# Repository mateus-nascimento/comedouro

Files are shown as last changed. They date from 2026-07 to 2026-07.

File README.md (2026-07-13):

# Comedouro — Alimentador de Pets com Porta RFID

Sistema de comedouro automatizado para gatos, com porta controlada por servo e leitora RFID 125 kHz serial. Apenas a tag da **Snow** abre a porta; qualquer outra tag cadastrada ou desconhecida fecha a porta.

---

## Funcionalidades e Comportamento

| Tag detectada | Ação |
|---|---|
| **Snow** (`900200000014659`) | Abre a porta (servo → 90°) |
| **Lilith** (`900200000014611`) | Fecha a porta (servo → 180°) |
| **Sophie** (`900200000014691`) | Fecha a porta (servo → 180°) |
| **Tag desconhecida** | Fecha a porta (servo → 180°) |

### Regras de operação

- A porta inicia **fechada** (180°) ao ligar o Arduino.
- O movimento do servo é **suave e gradual** (2° a cada 20 ms), sem travar o loop principal.
- Leituras RFID repetidas da **mesma tag** são ignoradas por **3 segundos** (debounce), evitando abertura/fechamento em loop.
- Se a porta **já está na posição desejada** (aberta ou fechada), uma nova leitura da mesma tag **não aciona o servo** — evita micro-movimentos ao reaproximar a tag.
- O **LED integrado** (pino 13) acende brevemente a cada tag processada com sucesso.
- O firmware **não usa `delay()`** — toda a lógica é baseada em polling e máquina de estados não-bloqueante.

---

## Requisitos de Hardware

| Componente | Função |
|---|---|
| **Arduino Uno** | Microcontrolador principal |
| **Servo MG90S** | Acionamento da porta do comedouro |
| **Leitora RFID 125 kHz serial** | Identificação das tags dos pets |
| **Fonte P4** | Alimentação do Arduino |
| **Protoboard 170 pontos** | Distribuição de 5V e GND para periféricos |

### Bibliotecas Arduino (IDE)

- `SoftwareSerial` (incluída no core do Arduino)
- `Servo` (incluída no core do Arduino)

---

## Diagrama de Ligação

### Alimentação

```
Fonte P4
  ├── (+) VIN  →  Arduino VIN (ou jack DC)
  └── (−) GND  →  Arduino GND
```

> A Fonte P4 alimenta o regulador interno do Arduino Uno, que fornece **5V** estável pelo pino `5V` e **GND** comum pelo pino `GND`.

### Distribuição via protoboard

```
Arduino 5V  ──→  Trilho (+) da protoboard 170 pontos
Arduino GND ──→  Trilho (−) da protoboard 170 pontos

Trilho (+) ──→  VCC da leitora RFID
Trilho (−) ──→  GND da leitora RFID

Trilho (+) ──→  VCC (fio vermelho) do Servo MG90S
Trilho (−) ──→  GND (fio marrom/preto) do Servo MG90S
```

> O servo e a leitora RFID são alimentados pelos trilhos da protoboard, que por sua vez recebem 5V e GND diretamente do Arduino. **Não** conecte a Fonte P4 diretamente aos periféricos — use sempre o regulador do Arduino.

### Conexões de sinal (Arduino)

| Pino Arduino | Destino | Observação |
|---|---|---|
| **D2** | TX da leitora RFID | Recepção via `SoftwareSerial` (`RFID_RX_PIN`) |
| **D3** | — | Reservado pelo `SoftwareSerial` (`RFID_TX_PIN`); não utilizado, mas obrigatório |
| **D10** | Sinal (fio laranja/amarelo) do Servo MG90S | Controle PWM do servo |
| **D13** | LED integrado | Indicador de leitura RFID processada |

### Diagrama ASCII completo

```
                    ┌─────────────────┐
                    │    Fonte P4     │
                    │   (+)      (−)  │
                    └────┬──────┬─────┘
                         │      │
                       VIN    GND
                         │      │
              ┌──────────┴──────┴──────────┐
              │       Arduino Uno        │
              │                          │
              │  D2 ◄──── TX  RFID       │
              │  D3  (reservado)         │
              │  D10 ────► SIG  Servo    │
              │  D13  LED integrado      │
              │                          │
              │  5V ──────────────┐      │
              │  GND ─────────────┼──┐   │
              └───────────────────┼──┼───┘
                                  │  │
              ┌───────────────────┴──┴───────────────────┐
              │         Protoboard 170 pontos              │
              │  Trilho (+)              Trilho (−)        │
              └──┬──────────────────────────┬──────────────┘
                 │                          │
           ┌─────┴─────┐              ┌─────┴─────┐
           │  RFID     │              │  RFID     │
           │  VCC  GND │              │  Servo    │
           │  TX       │              │  VCC  GND │
           └───────────┘              │  SIG      │
                                      └───────────┘
```

---

## Arquitetura de Software

O firmware é organizado em funções modulares com responsabilidades bem definidas. O `loop()` principal executa apenas duas tarefas em cada iteração:

```cpp
void loop() {
    updateServoPosition();  // Movimento gradual do servo
    pollRfid();             // Leitura não-bloqueante do RFID
}
```

### Módulos principais

| Módulo | Funções | Responsabilidade |
|---|---|---|
| **RFID** | `pollRfid`, `pollPacketReader`, `extractTag`, `parsePacket`, `buildTag` | Captura e decodificação de pacotes seriais |
| **Porta** | `requestDoorOpen`, `requestDoorClose` | Define o ângulo alvo do servo conforme a tag |
| **Servo** | `updateServoPosition`, `moveServoOneStep` | Movimento suave não-bloqueante |
| **Debounce** | `isDebounced`, `rememberProcessedTag` | Evita leituras duplicadas em curto intervalo |
| **Conversão** | `u16ToString`, `u64ToString`, `nationalToString` | Monta string da tag a partir do pacote binário |

### Máquina de estados RFID (não-bloqueante)

A leitura do pacote serial usa uma máquina de estados com dois estados:

```
Idle ──(byte 0xAA)──► Reading ──(byte 0xBB)──► pacote completo → Idle
  ▲                        │
  └──── timeout 200 ms ────┘
```

1. **Idle** — aguarda o byte de início `0xAA` no buffer serial.
2. **Reading** — acumula bytes até encontrar `0xBB` (fim do pacote) ou estourar o timeout de 200 ms.
3. Pacote completo é parseado: bytes 4–5 = código do país, bytes 6–10 = número nacional (12 dígitos com zero-padding).

Essa abordagem garante que o servo continue se movendo suavemente enquanto o RFID é lido, sem nenhuma chamada a `delay()`.

### Protocolo do pacote RFID

| Campo | Posição no pacote | Descrição |
|---|---|---|
| Byte de início | `[0]` | `0xAA` |
| Byte de fim | último byte | `0xBB` |
| Código do país | `[4]` e `[5]` | 16 bits, big-endian |
| Número nacional | `[6]` a `[10]` | 40 bits, big-endian |
| Tag final | — | `código_país` + `número_nacional` (12 dígitos) |

Exemplo: país `9002` + nacional `000014659` → tag `900200000014659` (Snow).

---

## Tabela de Constantes de Configuração

| Constante | Valor | Descrição |
|---|---|---|
| `RFID_RX_PIN` | `2` | Pino de recepção serial do RFID |
| `RFID_TX_PIN` | `3` | Pino TX reservado pelo `SoftwareSerial` |
| `SERVO_PIN` | `10` | Pino PWM do servo |
| `STATUS_LED_PIN` | `LED_BUILTIN` | LED integrado (pino 13 no Uno) |
| `SERVO_OPEN_ANGLE` | `90` | Ângulo com porta aberta |
| `SERVO_CLOSED_ANGLE` | `180` | Ângulo com porta fechada |
| `SERVO_STEP` | `2` | Graus movidos por iteração |
| `SERVO_STEP_INTERVAL_MS` | `20` | Intervalo entre passos do servo (ms) |
| `DEBOUNCE_MS` | `3000` | Tempo de debounce por tag (ms) |
| `START_BYTE` | `0xAA` | Byte de início do pacote RFID |
| `END_BYTE` | `0xBB` | Byte de fim do pacote RFID |
| `MAX_PACKET_SIZE` | `64` | Tamanho máximo do buffer de pacote |
| `BYTE_TIMEOUT_MS` | `200` | Timeout entre bytes durante leitura (ms) |
| `NATIONAL_DEC_WIDTH` | `12` | Largura do número nacional (dígitos) |
| Baud rate RFID | `9600` | Velocidade da porta serial (`rfidSerial.begin`) |

### Tempo de movimento do servo

Com as configurações padrão, a porta leva aproximadamente **900 ms** para percorrer os 90° entre fechado e aberto:

```
90° ÷ 2°/passo = 45 passos × 20 ms = 900 ms
```

---

## Tags Cadastradas

| Pet | Constante no código | ID da tag |
|---|---|---|
| Lilith | `TAG_LILITH` | `900200000014611` |
| Snow | `TAG_SNOW` | `900200000014659` |
| Sophie | `TAG_SOPHIE` | `900200000014691` |

Para adicionar ou alterar uma tag, edite as constantes no início de `comedouro.ino` e faça novo upload para o Arduino.

---

## Instruções de Upload

1. Instale o [Arduino IDE](https://www.arduino.cc/en/software) (versão 1.8.x ou 2.x).
2. Conecte o Arduino Uno ao computador via cabo USB.
3. Abra o arquivo `comedouro.ino` no Arduino IDE.
4. Em **Ferramentas → Placa**, selecione **Arduino Uno**.
5. Em **Ferramentas → Porta**, selecione a porta COM correspondente ao Arduino.
6. Clique em **Verificar** (✓) para compilar e confirmar que não há erros.
7. Clique em **Carregar** (→) para enviar o firmware ao Arduino.
8. Após o upload, a porta deve iniciar **fechada** (servo em 180°). Aproxime a tag da Snow para testar a abertura.

> As bibliotecas `SoftwareSerial` e `Servo` já fazem parte do core do Arduino Uno — não é necessário instalar bibliotecas adicionais.

---

## Solução de Problemas

### Servo lento ou travado durante leitura RFID

**Sintoma:** o servo se move de forma irregular ou para completamente enquanto uma tag é lida.

**Causa:** versões anteriores do firmware usavam `delay()` ou leitura serial bloqueante, impedindo que `updateServoPosition()` fosse chamada com frequência suficiente.

**Solução implementada:** a leitura RFID foi reescrita como máquina de estados não-bloqueante (`pollPacketReader`). Cada iteração do `loop()` processa no máximo alguns bytes do serial e retorna imediatamente, permitindo que o servo avance 2° a cada 20 ms sem interrupção.

### Porta não abre com a tag da Snow

- Verifique se a tag exibe o ID `900200000014659` (pode ser confirmado com um leitor RFID no computador).
- Confirme que o fio **TX da leitora** está conectado ao **D2** do Arduino.
- Verifique a alimentação: trilho (+) da protoboard deve estar em 5V.
- Aguarde 3 segundos após a última leitura da mesma tag (debounce ativo).

### Porta não fecha

- Qualquer tag diferente de Snow deve fechar a porta — teste com Lilith ou Sophie.
- Verifique se o servo está recebendo alimentação adequada pelo trilho da protoboard.
- Confirme que o fio de sinal do servo está no **D10**.

### Leitora RFID não responde

- Baud rate deve ser **9600** (padrão do módulo e do firmware).
- Verifique GND comum entre Arduino, leitora e servo.
- Confirme que o pino **D3** não está sendo usado por outro componente (reservado pelo `SoftwareSerial`).
- Teste com LED integrado: se ele pisca ao aproximar uma tag, a leitora e o parsing estão funcionando.

### Servo não se move ou vibra

- O MG90S requer **5V** estáveis — alimentar pelo trilho da protoboard a partir do pino `5V` do Arduino é suficiente para um único servo.
- Verifique o fio de sinal (geralmente laranja ou amarelo) no **D10**.
- Ângulos configurados: aberto = 90°, fechado = 180°. Ajuste `SERVO_OPEN_ANGLE` e `SERVO_CLOSED_ANGLE` se a mecânica da porta exigir outros valores.

### Micro-movimento ao reaproximar a tag Snow com a porta já aberta

**Sintoma:** a porta já está aberta, mas ao afastar e aproximar a tag Snow novamente o servo se move levemente, como se tentasse abrir de novo.

**Causa:** após o debounce de 3 segundos, a tag Snow era reprocessada e o firmware não verificava se o servo já estava na posição de abertura (`currentServoAngle` e `targetServoAngle` em 90°).

**Solução implementada:** funções `isDoorAtOpenPosition()` e `isDoorAtClosedPosition()` garantem que comandos redundantes sejam ignorados. `handleDetectedTag()` só chama `requestDoorOpen()` ou `requestDoorClose()` quando há mudança de estado real.

### Tag lida repetidamente sem efeito

- O debounce de **3 segundos** bloqueia ações repetidas da mesma tag. Aguarde o intervalo ou aproxime uma tag diferente para forçar uma nova ação.

### Pacote RFID corrompido ou ignorado

- O timeout de **200 ms** entre bytes descarta pacotes incompletos automaticamente.
- Verifique interferência eletromagnética próxima ao módulo RFID.
- Certifique-se de que os fios de sinal não estão muito longos ou em paralelo com fios de alimentação de motores.

---

## Estrutura do Projeto

```
comedouro/
├── comedouro.ino   # Firmware principal
└── README.md       # Este arquivo
```

---

## Licença

Projeto de uso pessoal/doméstico. Livre para adaptar conforme necessário.

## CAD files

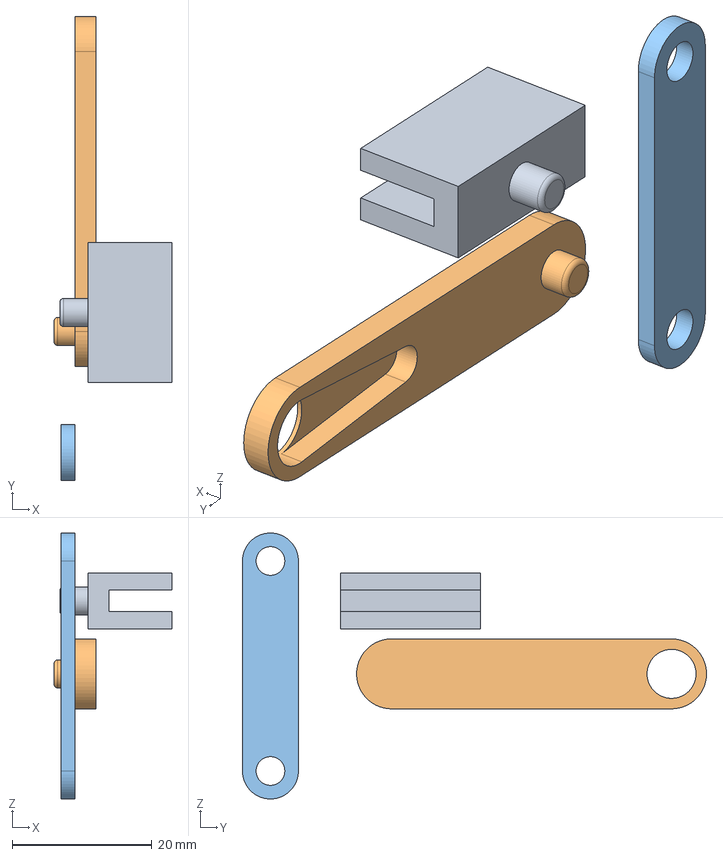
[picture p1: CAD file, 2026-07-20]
modelagem/comedouro-v2.FCStd
16.8 x 66.3 x 38.0 mm
clipe
alavanca
haste

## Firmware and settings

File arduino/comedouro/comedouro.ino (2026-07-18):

#include <SoftwareSerial.h>
#include <Servo.h>
#include <stdint.h>
#include <string.h>

// =====================================================
// Configuração de Hardware
// =====================================================
constexpr byte RFID_RX_PIN = 2;
constexpr byte RFID_TX_PIN = 3;      // Não utilizado, exigido pelo SoftwareSerial
constexpr byte SERVO_PIN = 10;
constexpr byte STATUS_LED_PIN = LED_BUILTIN;

// =====================================================
// Configuração do Servo
// =====================================================
constexpr int SERVO_OPEN_ANGLE = 145;
constexpr int SERVO_CLOSED_ANGLE = 0;

constexpr int SERVO_STEP = 2;
constexpr unsigned long SERVO_STEP_INTERVAL_MS = 20;

// =====================================================
// Configuração RFID
// =====================================================
constexpr unsigned long DEBOUNCE_MS = 3000UL;

constexpr uint8_t START_BYTE = 0xAA;
constexpr uint8_t END_BYTE = 0xBB;

constexpr size_t MAX_PACKET_SIZE = 64;
constexpr unsigned long BYTE_TIMEOUT_MS = 200;

constexpr int NATIONAL_DEC_WIDTH = 12;

// =====================================================
// Tags cadastradas
// =====================================================
constexpr char TAG_LILITH[] = "900200000014611";
constexpr char TAG_SNOW[]   = "900200000014659";
constexpr char TAG_SOPHIE[] = "900200000014691";

// =====================================================
// Objetos
// =====================================================
SoftwareSerial rfidSerial(RFID_RX_PIN, RFID_TX_PIN);
Servo doorServo;

// =====================================================
// Estado da Porta
// =====================================================
bool doorOpen = false;

// =====================================================
// Estado do Servo
// =====================================================
int currentServoAngle = SERVO_CLOSED_ANGLE;
int targetServoAngle = SERVO_CLOSED_ANGLE;

unsigned long lastServoUpdateTime = 0;

// =====================================================
// Controle de Debounce RFID
// =====================================================
char lastProcessedTag[32] = "";
unsigned long lastProcessedTime = 0;

// =====================================================
// Leitura não-bloqueante do pacote RFID
// =====================================================
enum class PacketReadState
{
    Idle,
    Reading
};

struct RfidReaderState
{
    PacketReadState state = PacketReadState::Idle;
    uint8_t buffer[MAX_PACKET_SIZE];
    size_t length = 0;
    unsigned long lastByteTime = 0;
};

RfidReaderState rfidReaderState;

// =====================================================

void setup()
{
    Serial.begin(115200);
    
    pinMode(STATUS_LED_PIN, OUTPUT);
    digitalWrite(STATUS_LED_PIN, LOW);

    rfidSerial.begin(9600);

    doorServo.attach(SERVO_PIN);
    doorServo.write(currentServoAngle);
}

void loop()
{
    updateServoPosition();
    pollRfid();
}

// =====================================================
// RFID
// =====================================================

void pollRfid()
{
    uint8_t packet[MAX_PACKET_SIZE];
    size_t length = 0;

    if (!pollPacketReader(rfidReaderState, packet, length))
    {
        return;
    }

    char tag[32];

    if (!extractTag(packet, length, tag, sizeof(tag)))
    {
        return;
    }

    if (isDebounced(tag))
    {
        return;
    }

    rememberProcessedTag(tag);
    handleDetectedTag(tag);
}

void handleDetectedTag(const char *tag)
{

    digitalWrite(STATUS_LED_PIN, HIGH);

    // Snow apenas abre.
    // Se já estiver totalmente aberta, não faz nada.
    if (strcmp(tag, TAG_SNOW) == 0)
    {
        if (isDoorAtOpenPosition())
        {
            digitalWrite(STATUS_LED_PIN, LOW);
            return;
        }
        requestDoorOpen();
    }
    else
    {
        // Lilith e Sophie apenas fecham.
        // Se já estiver totalmente fechada, não faz nada.
        if (isDoorAtClosedPosition())
        {
            digitalWrite(STATUS_LED_PIN, LOW);
            return;
        }
        requestDoorClose();
    }

    digitalWrite(STATUS_LED_PIN, LOW);
}

// =====================================================
// Controle da Porta
// =====================================================

bool isDoorAtOpenPosition()
{
    return currentServoAngle == SERVO_OPEN_ANGLE
        && targetServoAngle == SERVO_OPEN_ANGLE;
}

bool isDoorAtClosedPosition()
{
    return currentServoAngle == SERVO_CLOSED_ANGLE
        && targetServoAngle == SERVO_CLOSED_ANGLE;
}

void requestDoorOpen()
{
    if (isDoorAtOpenPosition())
    {
        doorOpen = true;
        return;
    }

    if (doorOpen && targetServoAngle == SERVO_OPEN_ANGLE)
    {
        return;
    }

    targetServoAngle = SERVO_OPEN_ANGLE;
    doorOpen = true;
}

void requestDoorClose()
{
    if (isDoorAtClosedPosition())
    {
        doorOpen = false;
        return;
    }

    if (!doorOpen && targetServoAngle == SERVO_CLOSED_ANGLE)
    {
        return;
    }

    targetServoAngle = SERVO_CLOSED_ANGLE;
    doorOpen = false;
}

// =====================================================
// Movimento Suave do Servo
// =====================================================

void updateServoPosition()
{
    if (currentServoAngle == targetServoAngle)
    {
        return;
    }

    if (millis() - lastServoUpdateTime < SERVO_STEP_INTERVAL_MS)
    {
        return;
    }

    lastServoUpdateTime = millis();

    moveServoOneStep();

    doorServo.write(currentServoAngle);
}

void moveServoOneStep()
{
    if (currentServoAngle < targetServoAngle)
    {
        currentServoAngle += SERVO_STEP;

        if (currentServoAngle > targetServoAngle)
        {
            currentServoAngle = targetServoAngle;
        }
    }
    else
    {
        currentServoAngle -= SERVO_STEP;

        if (currentServoAngle < targetServoAngle)
        {
            currentServoAngle = targetServoAngle;
        }
    }
}

// =====================================================
// Debounce
// =====================================================

bool isDebounced(const char *tag)
{
    if (strcmp(tag, lastProcessedTag) != 0)
    {
        return false;
    }

    return (millis() - lastProcessedTime) < DEBOUNCE_MS;
}

void rememberProcessedTag(const char *tag)
{
    strncpy(lastProcessedTag, tag, sizeof(lastProcessedTag));
    lastProcessedTag[sizeof(lastProcessedTag) - 1] = '\0';
    lastProcessedTime = millis();
}

// =====================================================
// Leitura do pacote RFID
// =====================================================

void resetPacketReader(RfidReaderState &reader)
{
    reader.state = PacketReadState::Idle;
    reader.length = 0;
}

bool pollPacketReader(RfidReaderState &reader, uint8_t *buffer, size_t &length)
{
    length = 0;

    if (reader.state == PacketReadState::Idle)
    {
        while (rfidSerial.available())
        {
            int value = rfidSerial.read();

            if (value == START_BYTE)
            {
                reader.buffer[0] = START_BYTE;
                reader.length = 1;
                reader.lastByteTime = millis();
                reader.state = PacketReadState::Reading;
                break;
            }
        }

        return false;
    }

    while (rfidSerial.available())
    {
        int value = rfidSerial.read();

        if (reader.length >= MAX_PACKET_SIZE)
        {
            resetPacketReader(reader);
            return false;
        }

        reader.buffer[reader.length++] = value;
        reader.lastByteTime = millis();

        if (value == END_BYTE)
        {
            length = reader.length;
            memcpy(buffer, reader.buffer, length);
            resetPacketReader(reader);
            return true;
        }
    }

    if (millis() - reader.lastByteTime > BYTE_TIMEOUT_MS)
    {
        resetPacketReader(reader);
    }

    return false;
}

// =====================================================
// Conversão do pacote para Tag
// =====================================================

bool extractTag(const uint8_t *packet, size_t length, char *tag, size_t tagSize)
{
    uint16_t country = 0;
    uint64_t national = 0;

    if (!parsePacket(packet, length, country, national))
    {
        return false;
    }

    buildTag(country, national, tag, tagSize);

    return true;
}

bool parsePacket(const uint8_t *packet, size_t length, uint16_t &country, uint64_t &national)
{
    if (length < 13)
    {
        return false;
    }

    country = (packet[4] << 8) | packet[5];

    national = 0;

    for (int i = 6; i <= 10; i++)
    {
        national <<= 8;
        national |= packet[i];
    }

    return true;
}

void buildTag(uint16_t country, uint64_t national, char *tag, size_t tagSize)
{
    char countryString[8];
    char nationalString[32];

    u16ToString(country, countryString, sizeof(countryString));
    nationalToString(national, nationalString, sizeof(nationalString));

    snprintf(tag, tagSize, "%s%s", countryString, nationalString);
}

// =====================================================
// Conversões
// =====================================================

void u16ToString(uint16_t value, char *output, size_t size)
{
    u64ToString(value, output, size);
}

void u64ToString(uint64_t value, char *output, size_t size)
{
    if (value == 0)
    {
        strncpy(output, "0", size);
        return;
    }

    char buffer[32];
    int index = 0;

    while (value > 0)
    {
        buffer[index++] = '0' + (value % 10);
        value /= 10;
    }

    for (int i = 0; i < index; i++)
    {
        output[i] = buffer[index - i - 1];
    }

    output[index] = '\0';
}

void nationalToString(uint64_t national, char *output, size_t size)
{
    char number[32];

    u64ToString(national, number, sizeof(number));

    int length = strlen(number);
    int padding = NATIONAL_DEC_WIDTH - length;

    if (padding < 0)
    {
        padding = 0;
    }

    memset(output, '0', padding);
    strcpy(output + padding, number);
}

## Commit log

2026-07-16 feat: adicionando modelagem 3d
    [comedouro.FCStd]
2026-07-20 arduino nano
    [comedouro-v1.FCStd, comedouro-v2.FCStd, comedouro.FCStd]
2026-08-23 suporte de parede
2026-10-11 ajuste angulos de fechamento e abertura
2026-10-11 Update README with image and wiring details
    Added an image and additional wiring instructions for the Nano.
